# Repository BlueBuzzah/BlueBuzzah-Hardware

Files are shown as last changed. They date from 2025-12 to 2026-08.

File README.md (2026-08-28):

# BlueBuzzah Hardware



Hardware design files for BlueBuzzah v3, a medical device research platform
implementing vibrotactile Coordinated Reset (vCR) therapy for Parkinson's
disease research. This repository contains the files needed to manufacture the
physical components: PCB fabrication files, the board 3D model, and links to the
full build documentation.

## Overview

BlueBuzzah consists of two synchronized haptic gloves that deliver precisely
timed vibration patterns to the fingertips. Each glove requires:

- **Custom PCB** built around the Seeed XIAO ESP32-S3 (MCU + BLE), with five
  DRV2605L haptic drivers, a TCA9548A I2C multiplexer, an LSM6DS3 IMU, a
  WS2812B status LED, and five LRA motors (index, middle, ring, pinky, thumb)
- **Firmware** from the [BlueBuzzah-Firmware](https://github.com/BlueBuzzah/BlueBuzzah-Firmware) repository
- **Enclosure** — the v3 wearable enclosure has not been designed yet; see the
  wiki's Build Status page for the current state of the build

The board arrives fully assembled from JLCPCB's SMT service, and the tactor's
wire-to-LRA connection is a friction fit made by a 3D-printed wire plug — there
is no soldering anywhere in the build.

## Repository Contents

| Folder | Description |
| --- | --- |
| **[PCB/v3/](PCB/v3/)** | Gerbers, BOM, pick-and-place (CPL), and KiCad sources for the v3 board |
| **[3D-Print-Models/](3D-Print-Models/)** | 3D model of the v3 board (`.step`) |
| **[archive/](archive/)** | Deprecated v2 hardware files, kept for historical reference only |

## Getting Started

The complete, step-by-step build guide lives in the
**[BlueBuzzah-Hardware wiki](https://github.com/BlueBuzzah/BlueBuzzah-Hardware/wiki)** —
start there before ordering parts.

### Manufacturing the PCB

The [`PCB/v3/`](PCB/v3/) folder contains everything needed for fabrication and
assembly:

- `jlc_pcb_gerbers.zip` — Gerber files for PCB manufacturing
- `BOM_JCLPCB_BlueBuzzah_v3.csv` — bill of materials
- `CPL_JLCPCB_BlueBuzzah_v3-all-pos.csv` — pick-and-place positions
- `kicad/` — KiCad schematic and PCB source files

Upload the Gerber zip, BOM, and CPL to JLCPCB's SMT assembly service to order the
board fully assembled. See the wiki's "Ordering the PCB" page for details.

## Related Repositories

- **[BlueBuzzah-Firmware](https://github.com/BlueBuzzah/BlueBuzzah-Firmware)** - Firmware for the BlueBuzzah gloves.
- **[BlueBuzzah-Updater](https://github.com/BlueBuzzah/BlueBuzzah-Updater)** - Desktop application for updating and configuring BlueBuzzah devices.

## License

MIT License - see [LICENSE](LICENSE) for details.

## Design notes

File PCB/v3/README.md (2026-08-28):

# PCB v3 Manufacturing Files

Fabrication-ready files for the BlueBuzzah v3 PCB.

## Contents

| File | Description |
| --- | --- |
| `jlc_pcb_gerbers.zip` | Gerber files for PCB manufacturing |
| `BOM_JCLPCB_BlueBuzzah_v3.csv` | Bill of materials with component specifications |
| `CPL_JLCPCB_BlueBuzzah_v3-all-pos.csv` | Pick-and-place positions for SMT assembly |
| **[kicad/](kicad/)** | KiCad schematic and PCB source files |

## Ordering the Board

Upload `jlc_pcb_gerbers.zip`, the BOM CSV, and the CPL CSV to your preferred PCB manufacturer's assembly service (e.g. JLCPCB) to order the board fully assembled. The files are already formatted for JLCPCB's SMT assembly workflow.

If you only need bare boards (no assembly), the gerber zip alone is sufficient — order components separately using the BOM.

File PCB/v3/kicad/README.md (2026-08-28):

# KiCad Source Files

The KiCad schematic and PCB design source for the BlueBuzzah v3 board, provided so the design is readable and archivable alongside the board you order.

## Contents

- `*.kicad_pro` - KiCad project file
- `*.kicad_sch` - top-level schematic, plus `Buzzer_Drivers.kicad_sch` (haptic driver sub-schematic)
- `*.kicad_pcb` - PCB layout
- `fp-lib-table`, `sym-lib-table` - KiCad library table references

## Important: This Project Will Not Open Cleanly

Opening this project in KiCad will **not** resolve all footprints and symbols. The design depends on a third-party component library tree that is deliberately not vendored into this repository (it carries its own license and is unrelated to this repository's MIT license).

To do actual schematic or PCB editing, work in the source project instead:

**[PentaBuzzer repository](https://github.com/BlueBuzzah/PentaBuzzer)**

These files exist here purely as a reference snapshot of the design that produced the manufacturing files in `PCB/v3/`.

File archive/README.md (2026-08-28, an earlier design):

# Archived — Deprecated v2 Hardware

These files belong to the **earlier v2 BlueBuzzah hardware** (Adafruit Feather
nRF52840, 4-channel board). They are kept for historical reference only and are
**not** part of a current build.

**Do not use these files for a new build.** The current hardware is BlueBuzzah
v3 — see [`PCB/v3/`](../PCB/v3/) and the
[BlueBuzzah-Hardware wiki](https://github.com/BlueBuzzah/BlueBuzzah-Hardware/wiki).

| File | Description |
| --- | --- |
| `PCB/Bluetooth_4-ch_Buzzah_v2.0_-_2-layer_v4.zip` | v2 PCB Gerber files |
| `PCB/bom.csv` | v2 bill of materials |
| `PCB/positions.csv` | v2 pick-and-place positions |
| `PCB/netlist.ipc` | v2 IPC netlist |
| `Instructions/Blue Buzzah Build Documentation.pdf` | v2 build documentation |
| `3D-Print-Models/Blue Buzzah ABS Case and Tactors rev053125 NMD.stl` | v2 ABS enclosure (does not fit the v3 board) |

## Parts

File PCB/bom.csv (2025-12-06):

Designator | Footprint | Quantity | Value | LCSC Part #
A1 | Adafruit_Feather_WithMountingHoles | 1 | Adafruit_Feather_Generic_mountingholes
C1, C12, C13, C6, C7 | 0402 | 5 | 10u
C10, C11, C4, C5 | 0402 | 4 | 1u
C14, C2, C3, C8, C9 | 0402 | 5 | 0.1u
R1, R10, R11, R12, R2, R3, R4, R5, R6, R7, R8, R9 | 0402 | 12 | 10k
S1 | SW_EG1218 | 1 | EG1218
SP1, SP2, SP3, SP4, SP5, SP6, SP7, SP8 | PAD-2.5X2.5 | 8 | ~
SW2 | BTN_KMR2_4.6X2.8 | 1 | KMR2
U1 | SOP65P640X120-16N | 1 | TCA9546APWR
U2, U3, U4, U5 | VSSOP-10_3x3mm_P0.5mm | 4 | DRV2605LDGS

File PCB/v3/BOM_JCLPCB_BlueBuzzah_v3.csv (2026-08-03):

Comment | Designator | Footprint | JLCPCB Part #（optional）
Conn_01x02_Socket | J5,J2,J6,J4,J3,J1 | JST_PH_S2B-PH-K_1x02_P2.00mm_Horizontal | C5175239
1uF | C21,C2,C27,C24,C23,C18,C19,C20,C25,C26,C22 | C_0402_1005Metric | C52923
DRV2605LDGS | U8,U13,U14,U12,U11 | VSSOP-10_3x3mm_P0.5mm | C527464
100nF | C28,C32,C31,C1,C29,C30 | C_0402_1005Metric | C1525
PESD5V0L1UL | D2 | D_SOD-882 | C3001948
4.7k | R4,R19,R34,R23,R43,R41,R35,R3,R29,R28,R42,R27,R32,R5,R31,R45,R1,R30,R2,R25,R55,R44,R26 | R_0402_1005Metric | C25900
TCA9548APWR | U7 | TSSOP-24_4.4x7.8mm_P0.65mm | C130026
XIAO-ESP32-S3-SMD | U2 | XIAO-ESP32S3-SMD | C20467913
LSM6DS3 | U1 | LGA-14_3x2.5mm_P0.5mm_LayoutBorder3x4y | C967633
WS2812B RGB LED | D1 | LED_WS2812B_PLCC4_5.0x5.0mm_P3.2mm | C2761795
SW_SPDT | SW1 | SW_K3_1260D_L1_SPDT_Angled | C92657
22uF | C17 | C_1206_3216Metric | C12891

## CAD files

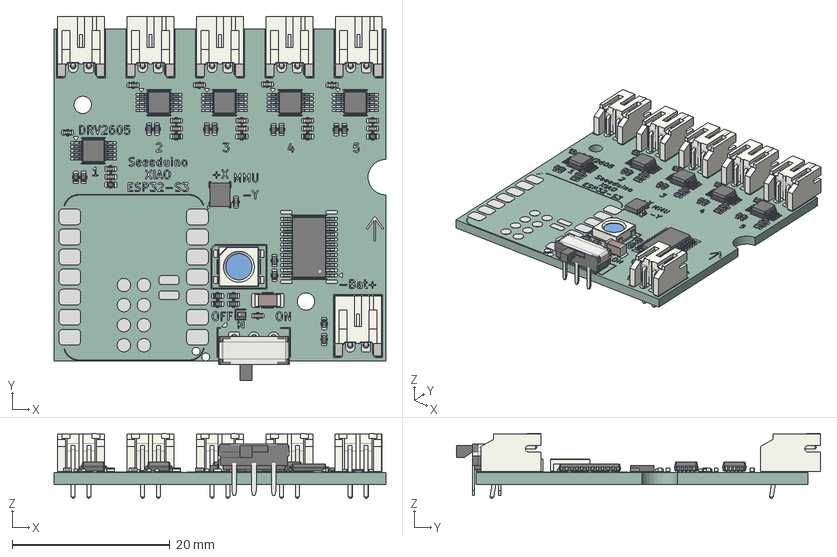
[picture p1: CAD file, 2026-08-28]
3D-Print-Models/BlueBuzzah_v3.step
42.0 x 46.1 x 8.25 mm
JST_PH_S2B-PH-K_1x02_P2.00mm_Horizontal x 6
C_0402_1005Metric x 17
VSSOP-10_3x3mm_P0.5mm x 5
D_SOD-882
R_0402_1005Metric x 23
TSSOP-24_4.4x7.8mm_P0.65mm
LGA-14_3x2.5mm_P0.5mm_LayoutBorder3x4y
LED_WS2812B_PLCC4_5.0x5.0mm_P3.2mm
SW_CK_JS202011AQN_DPDT_Angled
C_1206_3216Metric
BlueBuzzah_v3_pad
BlueBuzzah_v3_silkscreen
BlueBuzzah_v3_PCB

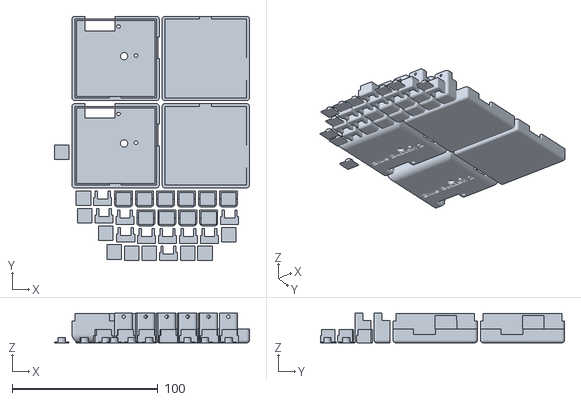
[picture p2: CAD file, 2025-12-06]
3D-Print-Models/Blue Buzzah ABS Case and Tactors rev053125 NMD.stl
134.0 x 168.0 x 20.4

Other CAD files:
3D-Print-Models/Penta_Buzzer_mini_V2_2_single_side.step

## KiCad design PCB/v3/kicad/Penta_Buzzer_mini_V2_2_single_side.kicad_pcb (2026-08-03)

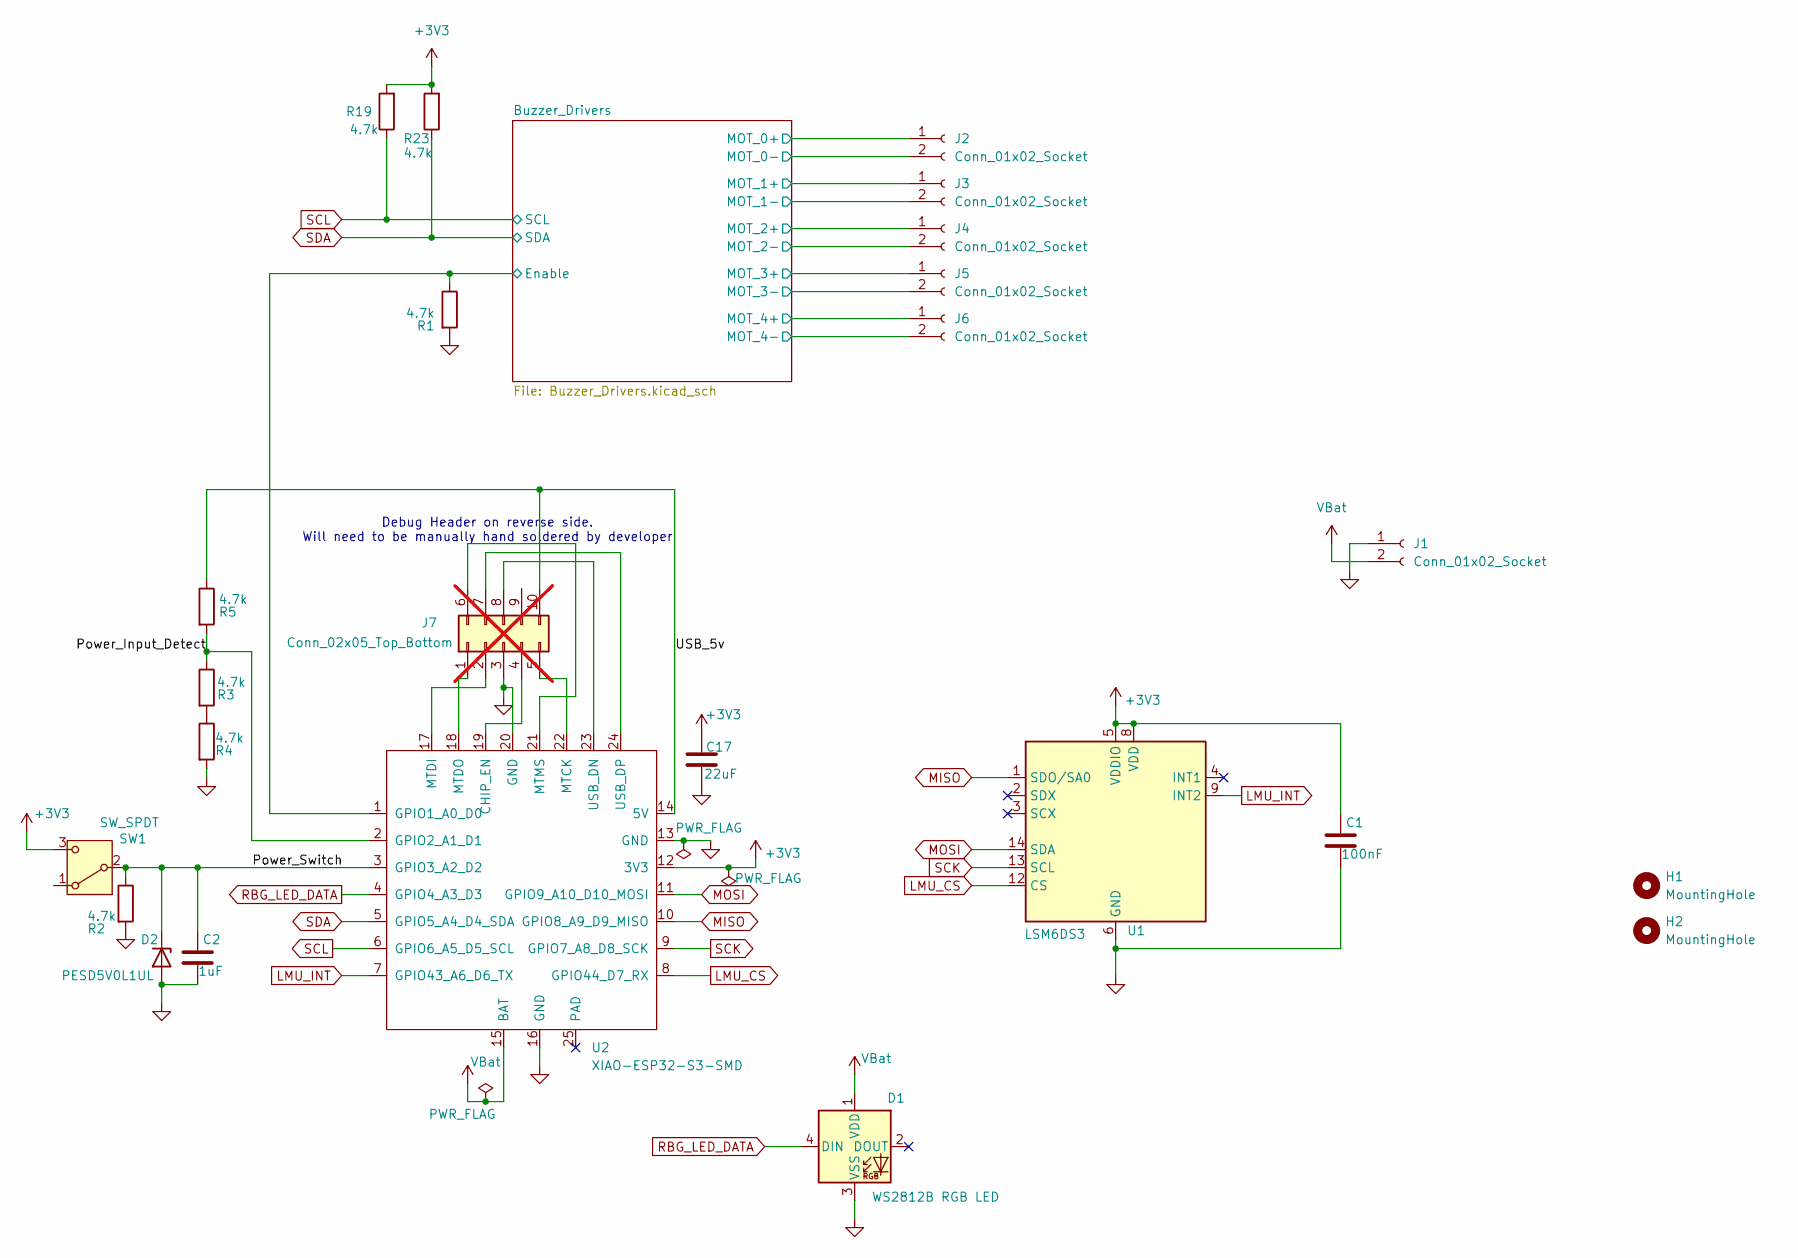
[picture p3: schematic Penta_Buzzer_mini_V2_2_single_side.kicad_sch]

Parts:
C1: 100nF; C_0402_1005Metric
C2: 1uF; C_0402_1005Metric
C17: 22uF; C_1206_3216Metric
D1: WS2812B RGB LED; LED_WS2812B_PLCC4_5.0x5.0mm_P3.2mm
D2: PESD5V0L1UL; D_SOD-882
H1, H2: MountingHole; MountingHole_2.2mm_M2
J1, J2, J3, J4, J5, J6: Conn_01x02_Socket; JST_PH_S2B-PH-K_1x02_P2.00mm_Horizontal
J7: Conn_02x05_Top_Bottom; PinHeader_2x05_P2.54mm_Vertical_SMD; not fitted
R1, R2, R3, R4, R5, R19, R23: 4.7k; R_0402_1005Metric
SW1: SW_SPDT; SW_K3_1260D_L1_SPDT_Angled
U1: LSM6DS3; LGA-14_3x2.5mm_P0.5mm_LayoutBorder3x4y
U2: XIAO-ESP32-S3-SMD; XIAO-ESP32S3-SMD

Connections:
+3V3: C1.1, C17.1, R19.2, R23.2, SW1.3 (C), U1.5 (VDDIO), U1.8 (VDD), U2.12 (3V3); also elsewhere on the board
/Buzzer_Drivers/Enable: R1.1, U2.1 (GPIO1_A0_D0); also elsewhere on the board
/Buzzer_Drivers/MOT_0+: J2.1; also elsewhere on the board
/Buzzer_Drivers/MOT_0-: J2.2; also elsewhere on the board
/Buzzer_Drivers/MOT_1+: J3.1; also elsewhere on the board
/Buzzer_Drivers/MOT_1-: J3.2; also elsewhere on the board
/Buzzer_Drivers/MOT_2+: J4.1; also elsewhere on the board
/Buzzer_Drivers/MOT_2-: J4.2; also elsewhere on the board
/Buzzer_Drivers/MOT_3+: J5.1; also elsewhere on the board
/Buzzer_Drivers/MOT_3-: J5.2; also elsewhere on the board
/Buzzer_Drivers/MOT_4+: J6.1; also elsewhere on the board
/Buzzer_Drivers/MOT_4-: J6.2; also elsewhere on the board
/Power_Input_Detect: R3.1, R5.2, U2.2 (GPIO2_A1_D1)
/Power_Switch: C2.1, D2.1 (K), R2.1, SW1.2 (B), U2.3 (GPIO3_A2_D2)
/USB_5v: J7.10, R5.1, U2.14 (5V)
GND: C1.2, C2.2, C17.2, D1.3 (VSS), D2.2 (A), J1.1, J7.3, R1.2, R2.2, R4.2, U1.6 (GND), U1.7 (GND), U2.13 (GND), U2.16 (GND), U2.20 (GND); also elsewhere on the board
LMU_CS: U1.12 (CS), U2.8 (GPIO44_D7_RX)
LMU_INT: U1.9 (INT2), U2.7 (GPIO43_A6_D6_TX)
MISO: U1.1 (SDO/SA0), U2.10 (GPIO8_A9_D9_MISO)
MOSI: U1.14 (SDA), U2.11 (GPIO9_A10_D10_MOSI)
unnamed: J7.1, U2.18 (MTDO)
unnamed: J7.2, U2.17 (MTDI)
unnamed: J7.4, U2.19 (CHIP_EN)
unnamed: J7.5, U2.22 (MTCK)
unnamed: J7.6, U2.21 (MTMS)
unnamed: J7.7, U2.24 (USB_DP)
unnamed: J7.8, U2.23 (USB_DN)
unnamed: R3.2, R4.1
RBG_LED_DATA: D1.4 (DIN), U2.4 (GPIO4_A3_D3)
SCK: U1.13 (SCL), U2.9 (GPIO7_A8_D8_SCK)
SCL: R19.1, U2.6 (GPIO6_A5_D5_SCL); also elsewhere on the board
SDA: R23.1, U2.5 (GPIO5_A4_D4_SDA); also elsewhere on the board
VBat: D1.1 (VDD), J1.2, U2.15 (BAT); also elsewhere on the board

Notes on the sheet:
Debug Header on reverse side. Will need to be manually hand soldered by developer

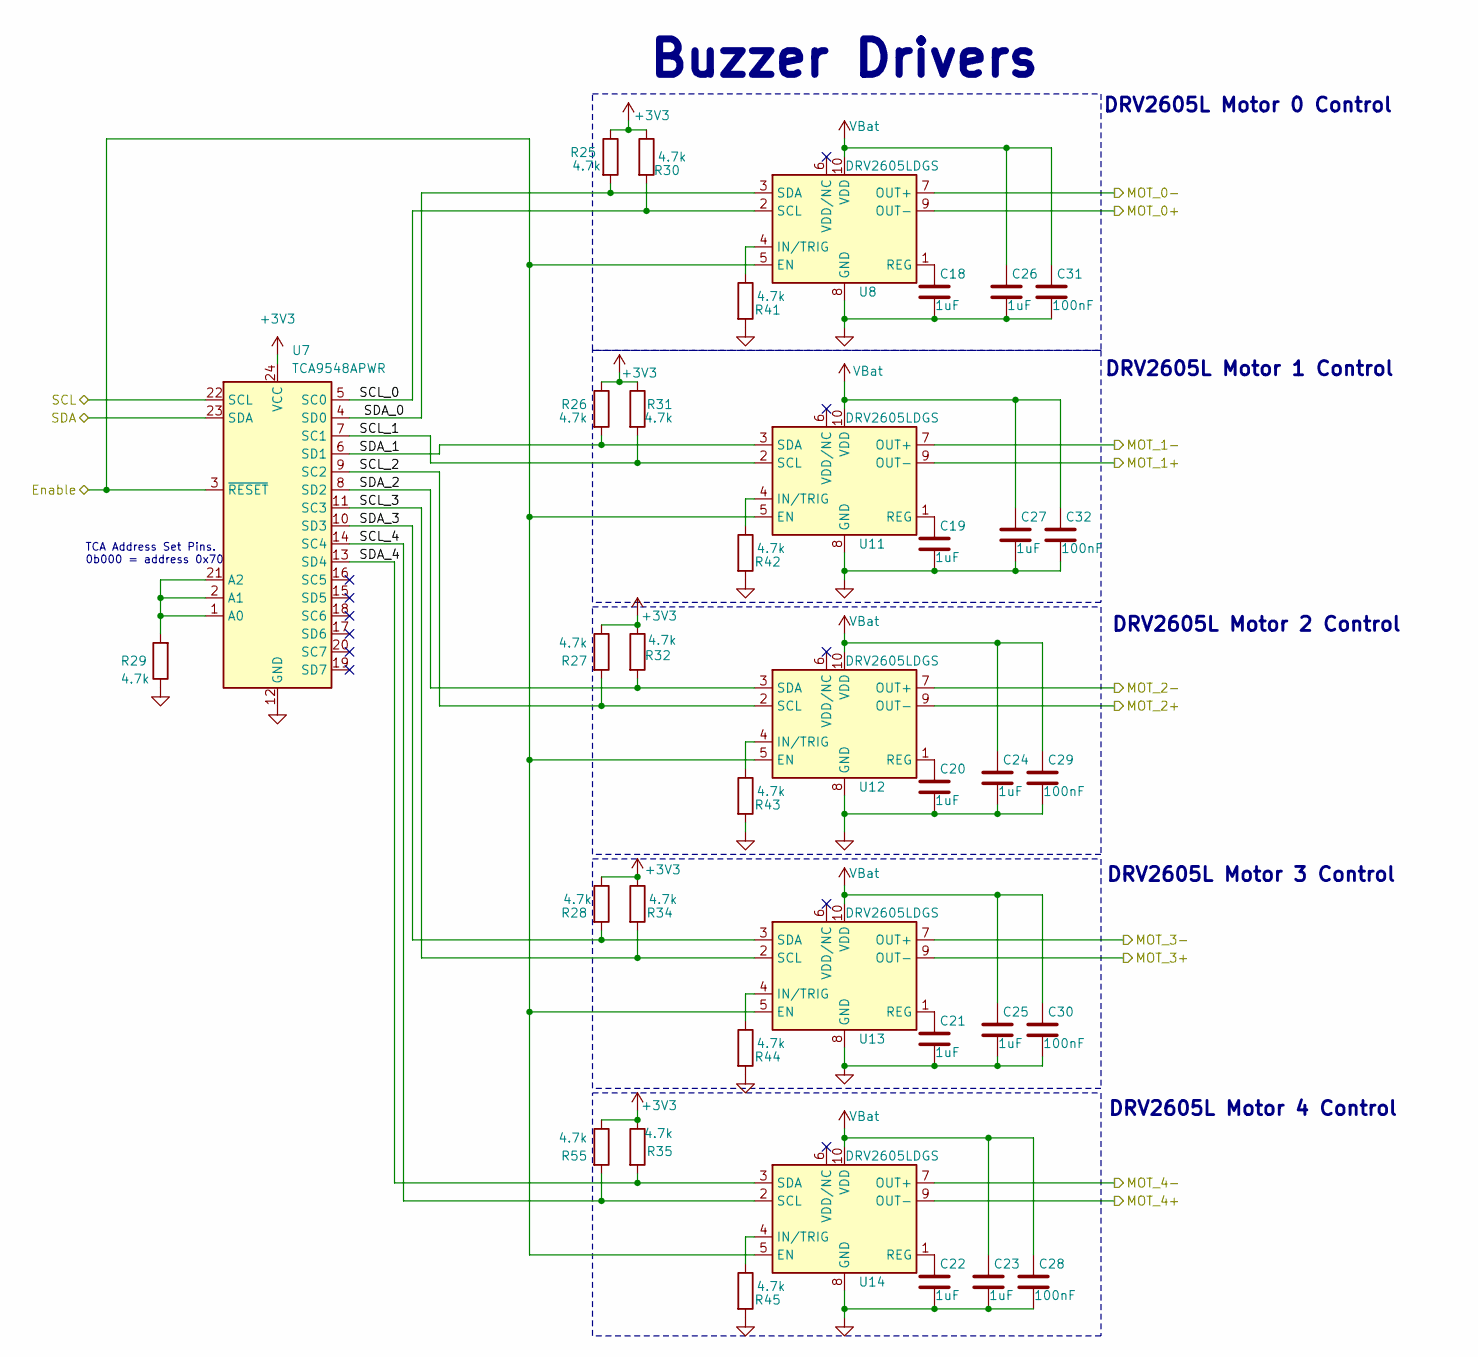
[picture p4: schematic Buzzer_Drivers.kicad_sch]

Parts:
C18, C19, C20, C21, C22, C23, C24, C25, C26, C27: 1uF; C_0402_1005Metric
C28, C29, C30, C31, C32: 100nF; C_0402_1005Metric
R25, R26, R27, R28, R29, R30, R31, R32, R34, R35, R41, R42, R43, R44, R45, R55: 4.7k; R_0402_1005Metric
U7: TCA9548APWR; TSSOP-24_4.4x7.8mm_P0.65mm
U8, U11, U12, U13, U14: DRV2605LDGS; VSSOP-10_3x3mm_P0.5mm

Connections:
+3V3: R25.1, R26.1, R27.1, R28.1, R30.1, R31.1, R32.1, R34.1, R35.1, R55.1, U7.24 (VCC); also elsewhere on the board
/Buzzer_Drivers/Enable: U7.3 (~RESET), U8.5 (EN), U11.5 (EN), U12.5 (EN), U13.5 (EN), U14.5 (EN); also elsewhere on the board
/Buzzer_Drivers/MOT_0+: U8.9 (OUT-); also elsewhere on the board
/Buzzer_Drivers/MOT_0-: U8.7 (OUT+); also elsewhere on the board
/Buzzer_Drivers/MOT_1+: U11.9 (OUT-); also elsewhere on the board
/Buzzer_Drivers/MOT_1-: U11.7 (OUT+); also elsewhere on the board
/Buzzer_Drivers/MOT_2+: U12.9 (OUT-); also elsewhere on the board
/Buzzer_Drivers/MOT_2-: U12.7 (OUT+); also elsewhere on the board
/Buzzer_Drivers/MOT_3+: U13.9 (OUT-); also elsewhere on the board
/Buzzer_Drivers/MOT_3-: U13.7 (OUT+); also elsewhere on the board
/Buzzer_Drivers/MOT_4+: U14.9 (OUT-); also elsewhere on the board
/Buzzer_Drivers/MOT_4-: U14.7 (OUT+); also elsewhere on the board
/Buzzer_Drivers/SCL_0: R30.2, U7.5 (SC0), U8.2 (SCL)
/Buzzer_Drivers/SCL_1: R31.2, U7.7 (SC1), U11.2 (SCL)
/Buzzer_Drivers/SCL_2: R27.2, U7.9 (SC2), U12.2 (SCL)
/Buzzer_Drivers/SCL_3: R34.2, U7.11 (SC3), U13.2 (SCL)
/Buzzer_Drivers/SCL_4: R55.2, U7.14 (SC4), U14.2 (SCL)
/Buzzer_Drivers/SDA_0: R25.2, U7.4 (SD0), U8.3 (SDA)
/Buzzer_Drivers/SDA_1: R26.2, U7.6 (SD1), U11.3 (SDA)
/Buzzer_Drivers/SDA_2: R32.2, U7.8 (SD2), U12.3 (SDA)
/Buzzer_Drivers/SDA_3: R28.2, U7.10 (SD3), U13.3 (SDA)
/Buzzer_Drivers/SDA_4: R35.2, U7.13 (SD4), U14.3 (SDA)
GND: C18.2, C19.2, C20.2, C21.2, C22.2, C23.2, C24.2, C25.2, C26.2, C27.2, C28.2, C29.2, C30.2, C31.2, C32.2, R29.1, R41.2, R42.2, R43.2, R44.2, R45.2, U7.12 (GND), U8.8 (GND), U11.8 (GND), U12.8 (GND), U13.8 (GND), U14.8 (GND); also elsewhere on the board
unnamed: R29.2, U7.1 (A0), U7.2 (A1), U7.21 (A2)
unnamed: R41.1, U8.4 (IN/TRIG)
unnamed: C18.1, U8.1 (REG)
unnamed: R42.1, U11.4 (IN/TRIG)
unnamed: C19.1, U11.1 (REG)
unnamed: R43.1, U12.4 (IN/TRIG)
unnamed: C20.1, U12.1 (REG)
unnamed: R44.1, U13.4 (IN/TRIG)
unnamed: C21.1, U13.1 (REG)
unnamed: R45.1, U14.4 (IN/TRIG)
unnamed: C22.1, U14.1 (REG)
SCL: U7.22 (SCL); also elsewhere on the board
SDA: U7.23 (SDA); also elsewhere on the board
VBat: C23.1, C24.1, C25.1, C26.1, C27.1, C28.1, C29.1, C30.1, C31.1, C32.1, U8.10 (VDD), U11.10 (VDD), U12.10 (VDD), U13.10 (VDD), U14.10 (VDD); also elsewhere on the board

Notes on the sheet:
DRV2605L Motor 2 Control
DRV2605L Motor 0 Control
TCA Address Set Pins. 0b000 = address 0x70
DRV2605L Motor 3 Control
DRV2605L Motor 4 Control
DRV2605L Motor 1 Control
Buzzer Drivers

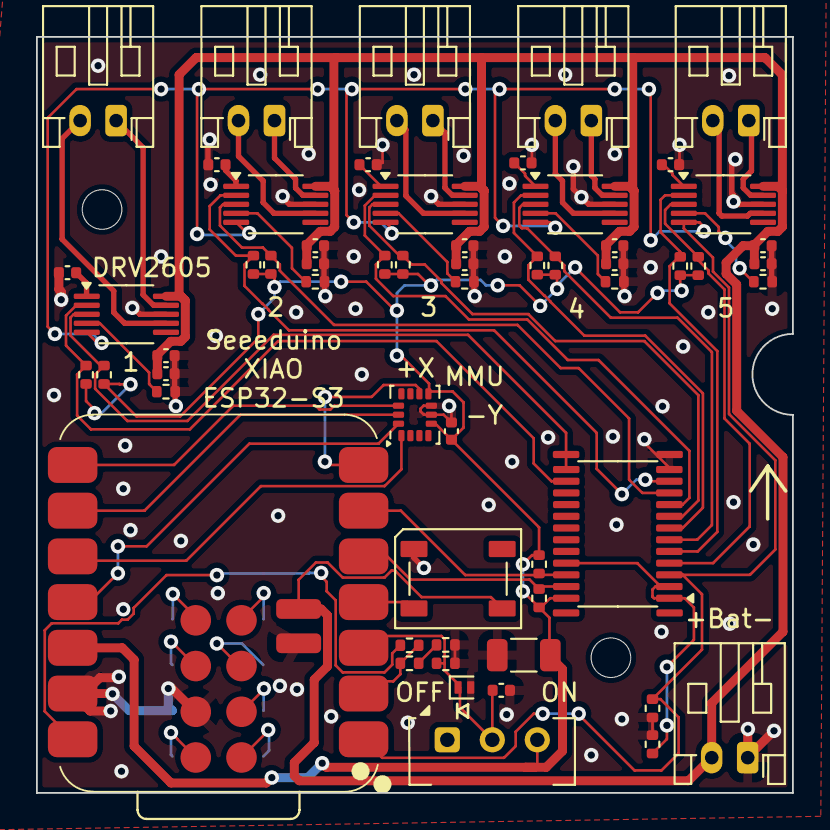
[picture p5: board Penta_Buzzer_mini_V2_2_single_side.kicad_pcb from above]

Board: 2 copper layers, 42.0 x 42.0 mm, 61 parts (1 on the bottom side), 54 nets.

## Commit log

2025-12-06 Initial commit of existing resources and documentation
    [Blue Buzzah ABS Case and Tactors rev053125 NMD.stl, bom.csv, positions.csv]
2026-07-31 docs: revise v3 wiki spec from team review
    - Reorder build sequence so flashing and a bare-board smoke test precede
    all irreversible assembly (tactor soldering, housing glue-up, glove cuts)
    - Resolve scope contradiction: guide is complete through bench test, not
    wearable daily use, pending enclosure design
    - Scope the asset copy precisely; exclude the 18MB third-party Libraries
    tree and its nested licenses
    - Add procedural dry-run and parts-quantity reconciliation to verification
    - Specify Part-9 coverage: pairing, sync verification, firmware updates
    - Add page boundaries, handedness, cost estimate, charging
2026-07-31 docs: support v2 owners via sanctioned PDF link; scope out LiPo safety
    - v2 owners formally supported by one deliberate exception: a link to the
    archived build PDF from Home and Parts-and-Tools-List
    - Link check allowlists that exact path so the sanctioned link passes while
    all other v2 references still fail
    - LiPo safety guidance explicitly out of scope
2026-07-31 feat: add v3 PCB manufacturing files, KiCad source, and board model
    [BOM_JCLPCB_Penta_Buzzer_mini_V2_2_single_side.csv, Buzzer_Drivers.kicad_sch, Penta_Buzzer_mini_V2_2_single_side.kicad_pcb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]
2026-07-31 docs: stage explicit paths in wiki commits to protect uncommitted owner edit
2026-08-28 docs: deprecate v2 hardware, align repo to v3
    Archive the v2 PCB (4-ch Buzzah v2.0 gerbers, BOM, positions, netlist), the
    v2 build PDF, and the v2 ABS case STL under archive/ with a README marking
    them deprecated and not for new builds.
    Rewrite the repo README for the v3 board (Seeed XIAO ESP32-S3, DRV2605L x5,
    TCA9548A, LSM6DS3, WS2812B) and point build docs to the wiki instead of the
    old PDF. Update wiki_check.py to forbid the v2 build PDF/video links while
    allowing v2 context that steers builders away from mistakes.
    [Blue Buzzah ABS Case and Tactors rev053125 NMD.stl, bom.csv, positions.csv]
2026-08-28 docs: correct build to solder-free (friction-fit wire plug)
    The tactor's wire-to-LRA connection is a friction fit made by the 3D-printed
    wire plug (Part 4, Step 2), not a solder joint. Fix the README's inaccurate
    "only soldering is wires onto the LRA terminals" claim accordingly.
2026-08-28 docs: rename builder-facing files from PentaBuzzer to BlueBuzzah v3
    Rename the board model and JLCPCB export files to BlueBuzzah v3 (their
    content does not depend on the filename) and scrub the .step internal
    labels: BlueBuzzah_v3.step, BOM_JCLPCB_BlueBuzzah_v3.csv,
    CPL_JLCPCB_BlueBuzzah_v3-all-pos.csv. Update every doc reference and drop
    the "ignore the filename" explainers.
    The KiCad project files, the gerber zip internals, and the board silkscreen
    keep the upstream "Penta Buzzer" name — renaming those safely requires a
    KiCad Save-As and gerber re-plot, not a text edit.
    Also stop tracking the internal docs/superpowers/ planning files (already
    gitignored); they remain on disk and in his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
    [BOM_JCLPCB_BlueBuzzah_v3.csv, BlueBuzzah_v3.step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]
2026-11-02 assets(models): add updated 3D printed part part files
2026-11-03 chore: move the 3D models and render scripts from the wiki
    The .glb models go in models/ beside the CAD files, and the render
    pipeline goes in scripts/. Renders now default to this checkout and
    land in images/, which is ignored: the published copies are WebP files
    on BlueBuzzah.com.
2026-11-04 feat(pcb): move the v3 board to the ESP32-S3-WROOM-1U module
    Replace the XIAO-based v3 KiCad project with the JLCPCB-assembled module
    design, renamed BlueBuzzah_v3. Add the framed panel, make_jlcpcb.py and the
    ordering steps, and regenerate the gerbers, BOM and CPL under their existing
    names so the website's download links keep working.
2026-11-04 chore(render): render the v3 board from the WROOM KiCad STEP
    The bluebuzzah-v3-pcb render now uses PCB/v3/kicad/BlueBuzzah_v3.step with
    a blue solder mask and a silver-grey module shield. KiCad has no 3D model
    for the USB-C connector (J10), so the render adds one (RoyalBlue54L demo,
    CERN-OHL-P v2); SW1 keeps the switch stand-in.
    The config no longer exports models/bluebuzzah-v3-pcb.glb: the exploded
    view and assembly images still use the XIAO board.
2026-11-04 chore(render): move the board models and renders to the WROOM v3 board
    Rebuild models/bluebuzzah-v3-pcb.glb and models/bluebuzzah-exploded.glb
    from PCB/v3/kicad/BlueBuzzah_v3.step (blue mask, silver-grey module
    shield, added USB-C, switch stand-in) instead of the XIAO board.
    The antenna step now plugs into the module's U.FL socket, the port
    diagram uses the new connector names, and the XIAO export is gone from
    the pipeline.
2026-11-04 fix(pcb): resolve the v3 design review findings
    Delete the four orphan paste pads beside U7. Move EN's R67 and C45 to pin 3,
    cutting the net from 46 mm to 2 mm, with a DRC rule for their courtyards. Change
    R5 to 6.8k so USB detect sits near 2.9 V, and regenerate the order files.
2026-11-04 chore(models): export the WROOM v3 board STEP with the USB-C connector
    Replaces the old XIAO board model. KiCad has no library model for J10, so
    the export uses models/USB_C_Receptacle_HRO_TYPE-C-31-M-12.step.
2026-11-04 docs: name the ESP32-S3-WROOM-1U-N8R8 module in the v3 board docs
2026-11-04 feat(pcb): replace the BOOT test points with a button
    Add SW2 (TS-1088-AR02016, JLCPCB C720477) on the BOOT net in place of TP1 and
    TP2, so a board with a dead USB connection can enter the ROM bootloader
    without tweezers. There's no RESET button: EN sits in the opposite corner, and
    replugging power does the same job.
    Regenerate the panel, order files and board STEP, and add the recovery steps
    to the v3 README.
2026-11-04 chore(models): rebuild the v3 board models with the BOOT button
2026-11-04 feat(pcb): cut the v3 3.3 V supply from the power switch
    Drive the regulator's enable pin from SW1 through a delay node, so the
    switch cuts 3.3 V about 2 seconds after it's slid off, even if the
    firmware has stopped running. The delay gives the firmware time to stop
    the motors and save the session.
    - Feed SW1 from VBat and move U23 EN onto the new SW_EN net
    - Add R70 (220 k) and raise R2 to 1 M to divide SW_EN down to GPIO3
    - Swap the C2 and R2 positions and route +3V3 clear of SW1
    - Regenerate the JLCPCB order files and panel
    - Update the recovery steps in the README
2026-11-04 chore(models): rebuild the v3 board models with the hard power cut
2026-11-04 feat(pcb): make the power-switch shutdown window deterministic
    Ground SW1's spare throw so the switch common (SW_COM) drops the moment
    the switch slides off, and feed the regulator's EN through R71 (1M) into
    C2 (1 uF) so the 3.3 V supply cuts 1.4 to 2.2 s later. GPIO3 now reads
    SW_COM through R70 (270k) and R2, so the firmware sees the slide at once
    instead of watching the same decaying node as the regulator. IO3 sits at
    3.31 V on a full cell and 2.60 V at the 3.3 V cutoff.
    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
2026-11-06 fix(scripts): put v3 motor port labels in finger order
    Firmware now maps index to port 1 and thumb to port 5, so the labeled
    board render must match.
2026-11-06 feat(pcb): add PCBWay order files for the v3 board
    Add a separate PCBWay package for one bare board, not panelized. The
    JLCPCB files can't be reused: they come from the panel, and their CPL
    is corrected for JLCPCB's parts library.
    make_pcbway.py builds the gerbers, BOM and centroid from the KiCad
    sources. All outputs measure from the board's lower-left corner, set
    on a temporary copy so the KiCad project is untouched. The BOM carries
    manufacturer part numbers, and the centroid uses footprint origins and
    KiCad rotations.
    pcbway/ORDERING.md lists the order options and a panel note for
    PCBWay's rails, since the connectors overhang the top and bottom edges.
    The README links the new package.
2026-11-06 fix(pcb): clear solder pads and isolate GPIO2 from USB detection
2026-11-06 chore(pcb): rebuild the v3 order files and keep tabs clear of C43 and C44
2026-11-06 fix(models): clear the v3 case for the board's USB-C port
2026-11-06 revert(models): restore the v3 case before the USB-C opening rework
2026-11-06 fix(models): move the v3 case's USB-C opening onto J10
    The opening sat about 4.6 mm off the connector on the v3 board. Slide the
    original funnel along the upper shell, rebuild the wall it left, re-cut the
    lower shell's notch on J10, and trim the switch's left side so it clears the
    plug. Rebuild the case .glb files from the new STEP.
2026-11-06 docs(pcb): note the in-pad vias and point the DRV2605L at its frozen footprint
2026-11-06 chore(models): rebuild the v3 board models with the pad and via fixes
2026-11-07 fix(pcb): match the battery polarity of the working v3 boards
    Pin 1 is VBat and pin 2 GND again, with the silk back to -Bat+, as on the
    boards built from the March gerbers. The May gerbers swapped the two nets, so
    the batteries in use would have plugged in reversed. J1 keeps its place,
    rotation and part. Reroute the three VBat tracks and the GND link around it,
    and rebuild the JLCPCB and PCBWay gerbers.
2026-11-07 fix(pcb): clear D2's pad, tie ground pads to vias and reuse 5.1k for R5
    Move the GND via out of D2 pad 2, whose drill clipped the pad. Add tracks from
    seven ground pads to their nearest vias, so they no longer depend on the fill
    alone. R5 becomes 5.1k, a value already on the BOM, which puts USB detect at
    3.31 V and shortens the Q1 gate discharge.
2026-11-07 fix(pcb): straighten the autorouted zig-zags on five nets
    SCK, MISO, SCL_4, U14 IN/TRIG and Power_Switch still carried stair-steps from
    the autorouter. Replace them with 45-degree runs at the same width, keeping
    every pad, via and junction where it was.
2026-11-07 docs(schematic): explain the power circuits and fix label directions
    Note the charge current, Q1's gate pull-down and how SW1 cuts 3.3 V. Set each
    global label's direction, drop the U20 note's mention of the old build, and fix
    the RGB_LED_DATA spelling.
2026-11-07 docs(schematic): group MCU_Power into wired sections
    Split the sheet into USB, module, charger, power path and RGB LED sections,
    wiring local connections instead of labelling them. USB_5v and VBat_LED become
    power symbols, PWR_FLAGs move beside their sources, D1 joins Q2 and Q3 on this
    sheet, and text no longer overlaps. Connections are unchanged.
2026-11-07 docs(schematic): group the top sheet into sections
    Box the switch and USB detect, pull resistors, motor outputs, battery, bulk
    capacitor and IMU. Show R5 and R4 as a plain divider with R3 to the side, move
    the PWR_FLAG onto J1's ground, and clear the overlapping text. Connections are
    unchanged.
2026-11-07 chore(pcb): rebuild the v3 order files with the reviewer fixes
    Regenerate the panel, JLCPCB and PCBWay files. R5 merges into the 5.1k BOM
    line. Drop the JST alternate for J1 to J6, because the battery polarity on the
    working boards depends on the HDGC part.
2026-11-07 docs(pcb): tell PCBWay orders not to substitute J1 to J6
    Battery polarity was confirmed with the HDGC2001WR-2P, and another header might seat the plug differently.
2026-11-07 docs(pcb): add the unique part count to the PCBWay order notes
2026-11-07 fix(pcb): narrow U1's pads so PCBWay can keep its solder mask dams
    PCBWay needs 0.19 mm between pads for a mask dam, and U1's stock 0.35 mm pads leave 0.15 mm. Pads 5 and 6, and 7 and 8, put +3V3 beside GND, so a solder bridge there would stop the board starting. At 0.30 mm wide the gap is 0.20 mm. Rebuild the JLCPCB and PCBWay order files.
2026-11-10 feat(models): rework the v3 case's switch, snap and branding
    Recess BlueBuzzah.com into the upper shell top, with power-off and power
    icons beside a wider, centred power switch. Add a one-click snap between the
    shells and a wire exit at the bottom of the upper shell's back wall. Export
    the matching glb and STL files, add a test-print 3MF and the switch-fitted
    render config.
2026-11-10 feat(render): add a product render of two assembled devices
    Two closed cases, each with four tactor leads from ports 2 to 5 fanned out
    to finished tactors, seen from the front and above.
2026-11-10 docs(legal): license the board, models and docs separately
2026-11-10 feat(render): add the BuzzahBuddy.com hero render
    A phone showing BuzzahBuddy's Session screen between the two finished devices, with a perspective camera, studio light and a baked shadow on a transparent background. The screenshot is copied from the app's iOS store set so the config renders on its own.
2026-11-10 fix(render): fade the hero shadows out before the image edges
    The soft shadows reached past the frame, so the websites showed them cut off with hard edges. Widen the margin to 0.14 and fade the alpha to 0 over the outer 10% of the shorter side.
2026-11-10 fix(render): skip the hero render under --info and model export
    The hero hook rendered at full quality whenever it ran, so render.py --info did a full render instead of printing bounds. It now leaves the scene to brender whenever BB_MODE is set.
2026-11-10 fix(render): frame the hero renders tighter
    Margin 0.14 and fade 0.1 left about half of each hero image empty, so the hardware looked small on the websites. Margin 0.08 with a 0.07 fade lets the hardware fill about 84% of the width, and the shadows still fade out before every edge.
2026-11-12 feat(models): add an STL for each 3D-printed tactor part
    Meshes come from the BlueBuzzah-v3.3mf print project, so each part is in
    its print orientation and sits on the bed. The shell includes its two
    designed-in support bodies, and all three pin lengths are included.
2026-11-12 feat(models): open the v3 lower shell's back wall for the tactor plugs
    Remove the four tabs between the JST slots in the lower shell's back wall
    and cut one opening, x -21.0 to 21.0 and Z 8.5 to the rim, so a tactor plug
    pulls free instead of its wiring tearing. Only the lower shell's B-rep is
    replaced in the case STEP; the upper shell and switch are unchanged. Export
    the matching STL and glb files.
2026-11-12 feat(models): rename the v3 print file to BlueBuzzah-v3-parts.3mf
    Replace BlueBuzzah-v3.3mf with BlueBuzzah-v3-parts.3mf, which has the new
    lower shell. It has only the standard pin, so the pin-options render reads
    the short and long pins from the last committed BlueBuzzah-v3.3mf.
2026-11-12 fix(render): read the pin options from the tactor pin STLs
    The pin STLs on main replace reading the short and long pins from the old
    BlueBuzzah-v3.3mf in git.
2026-11-12 refactor(models): sort the model files into STEP, STL and GLB folders
    Move the STEP, STL and glb files into models/STEP, models/STL and
    models/GLB, rename the short and standard pin STLs to tactor-pin-xs and
    tactor-pin-sm, and the upper shell STL to upper-shell.stl. Point the render
    scripts, configs and READMEs at the new paths.
2026-11-12 refactor(pcb): build the v3 order files into an ignored build folder
    make_jlcpcb.py and make_pcbway.py now write to PCB/v3/build/jlcpcb/ and build/pcbway/, which git ignores, so the generated Gerbers, BOMs and placement files leave the repo. The files are renamed BlueBuzzah_v3_<vendor>_<kind>, which also fixes the JCLPCB typo and keeps the two packages apart once downloaded.
    The ordering notes move to PCB/v3/ORDERING-JLCPCB.md and ORDERING-PCBWay.md. The JLCPCB notes now follow the PCBWay layout, with an option table taken from JLCPCB's quote form: blue solder mask, ENIG, Panel by Customer 1 x 1, and the default via option.
2026-11-12 ci(release): attach the v3 parts and PCB zips to every release
    A published release builds the JLCPCB and PCBWay order files in the
    KiCad 10 container, then attaches BlueBuzzah-v3-parts.zip (case and
    tactor STLs, the 3mf, CC BY-SA) and BlueBuzzah-v3-PCB.zip (both order
    packages with their ordering notes, CERN-OHL-S), with build provenance.
2026-11-12 docs(pcb): write the ordering notes for the release zip
    The ordering notes now ship inside BlueBuzzah-v3-PCB.zip next to the
    built files, so they no longer send the reader to build/ or the make
    scripts. Part problems go to a GitHub issue, and the build and
    out-of-stock steps for maintainers move to PCB/v3/README.md, which now
    points people to the release zip for ordering.
2026-11-13 fix(models): remove the slivers at the v3 upper shell's switch end
    - Cut the fin of the rounded inner corner that stood in the switch
    relief, so the relief wall is one flat face.
    - Cut the thin skins of the corners left at the switch end of both
    snap grooves; the grooves now open cleanly into the corners.
    The STEP's stored precision values are restored after the FreeCAD
    export: written at FreeCAD's 1e-7, the upper shell reads back with
    gaps and meshes with holes.
